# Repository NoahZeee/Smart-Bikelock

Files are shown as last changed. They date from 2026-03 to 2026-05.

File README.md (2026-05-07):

# Smart Bike Lock - WiFi Hotspot Edition

A secure, wireless bike lock system controlled via a mobile web interface. Connect from any iOS or Android device to unlock/lock your bike through a dedicated WiFi hotspot.

## Features

- **📱 Mobile Web Interface**: Responsive web UI works on iOS, Android, and any browser
- **🔒 Password Protected**: Set custom passwords for lock control
- **📡 WiFi Hotspot**: Creates a local WiFi network (no internet required)
- **🔋 Deep Sleep**: Automatically sleeps after 5 minutes of inactivity for battery efficiency
- **💾 Persistent State**: Password and lock state saved to flash memory
- **⚡ Fast Control**: HTTP REST API with instant response times
- **🤖 Offline Operation**: No backend server or cloud connection required

## Hardware

- **Microcontroller**: ESP32 DOIT DevKit V1 (240MHz, 320KB RAM, 4MB Flash)
- **Motor**: 28BYJ-48 stepper motor with ULN2003A driver
- **Wakeup**: GPIO18 external interrupt (HIGH level trigger) or button press
- **GPIO Pins**:
  - Motor: 13, 25, 14, 26
  - Wakeup: 18
  - USB: COM6 (configurable in platformio.ini)

## Manufacturing Files

All files needed to manufacture the PCB and order parts are located in the **`hardware/`** directory:

### Schematics & PCB Layout
- **Location**: `hardware/schematics/`
- **Files**:
  - `RFID_bikelock.kicad_sch` - Schematic diagram
  - `RFID_bikelock.kicad_pcb` - PCB layout
  - `RFID_bikelock.csv` - Bill of Materials (BOM) - use this to order parts

### Gerber Files (for manufacturing)
- **Location**: `hardware/manufacturing/`
- **Files**:
  - `RFID_bikelock-F_Cu.gbr` - Front copper layer
  - `RFID_bikelock-B_Cu.gbr` - Back copper layer
  - `RFID_bikelock-F_Mask.gbr` - Front solder mask
  - `RFID_bikelock-B_Mask.gbr` - Back solder mask
  - `RFID_bikelock-F_Silkscreen.gbr` - Front silkscreen
  - `RFID_bikelock-B_Silkscreen.gbr` - Back silkscreen
  - `RFID_bikelock-Edge_Cuts.gbr` - Board edge cuts
  - `RFID_bikelock-job.gbrjob` - Gerber job file

### Drill Files
- **Location**: `hardware/manufacturing/`
- **Files**:
  - `RFID_bikelock-PTH.drl` - Plated through-hole drilling
  - `RFID_bikelock-NPTH.drl` - Non-plated through-hole drilling

### To Order PCBs
1. Use the Gerber files and drill files in `hardware/manufacturing/` 
2. Upload all files to your PCB manufacturer (JLCPCB, PCBWay, etc.)
3. Use the BOM (`hardware/schematics/RFID_bikelock.csv`) to order components

## Getting Started

### Prerequisites

- PlatformIO CLI or VS Code with PlatformIO extension
- USB cable for ESP32 upload
- Your smartphone on WiFi

### Building & Uploading

```bash
# Build firmware
platformio run

# Upload to ESP32
platformio run -t upload

# Monitor serial output
platformio run -t monitor
```

### Initial Setup

1. Serial monitor will display initialization sequence
2. Connect to WiFi network: `BikelockAP` (open network, no password)
3. Visit `http://192.168.4.1` from your phone
4. Set a password in the web UI (device will lock automatically)
5. Now you can lock/unlock with your password!

## Web UI Controls

- **Status Display**: Shows current lock state (🔒 LOCKED / 🔓 UNLOCKED)
- **Password Field**: Enter your password
- **Unlock Button**: Unlock the lock (requires correct password)
- **Lock Button**: Lock the device (only works when unlocked)
- **Set Password**: Set a new password and lock device
- **Refresh**: Manually refresh lock status
- **Reset Device**: Factory reset (clears password)

## REST API

All endpoints are available at `http://192.168.4.1`

### GET /status
Returns current lock state
```json
{"status": "LOCKED"}  // or "UNLOCKED"
```

### POST /unlock
Unlock with password
```json
Request: {"password": "your_password"}
Response: {"status": "UNLOCKED"}  // or stays "LOCKED" if password wrong
```

### POST /lock
Lock the device (requires password already set)
```json
Response: {"status": "LOCKED"}
```

### POST /set-password
Set new password and lock device
```json
Request: {"password": "new_password"}
Response: {"status": "LOCKED"}
```

### POST /reset
Factory reset device (clears password, unlocks)
```json
Response: {"status": "UNLOCKED"}
```

## Configuration

Edit `include/config.h` to customize:

- **WiFi Network**: `WIFI_SSID` and `WIFI_PASSWORD` (empty = open network)
- **Deep Sleep Timeout**: `INACTIVITY_TIMEOUT_MS` (default: 5 minutes)
- **Motor Rotation**: `STEPPER_LOCK_STEPS` and `STEPPER_UNLOCK_STEPS`
- **GPIO Pins**: All pin definitions
- **SPIFFS**: Flash partition configuration

## Project Structure

```
src/
├── main.cpp              # Setup and main event loop
├── wifi_server.cpp       # WiFi hotspot initialization
├── http_handlers.cpp     # HTTP endpoint handlers
├── commands.cpp          # Command processing logic
├── lock_control.cpp      # Stepper motor control
├── flash_storage.cpp     # SPIFFS persistence
└── globals.cpp           # Global variable definitions

include/
├── config.h              # Central configuration
├── globals.h             # Global declarations
├── web_ui.h              # Embedded HTML/CSS/JS UI
├── wifi_server.h         # WiFi function declarations
├── http_handlers.h       # HTTP handler declarations
├── commands.h            # Command processing declarations
├── lock_control.h        # Motor control declarations
└── flash_storage.h       # Storage function declarations
```

## How It Works

### Initialization Flow
1. ESP32 boots and mounts SPIFFS filesystem
2. Loads stored password and lock state from flash
3. Initializes stepper motor and rotates to match stored state
4. Enables GPIO18 for external wakeup (5V HIGH trigger)
5. Starts WiFi in Access Point (hotspot) mode
6. HTTP server listening on port 80
7. Enters main loop checking for inactivity

### Unlock Flow
1. User enters password in web UI
2. Browser sends POST to `/unlock` with JSON body
3. Server validates password matches stored value
4. If correct: rotates motor to unlock position, saves state
5. If incorrect: returns current state (still LOCKED)
6. Browser receives response and updates UI accordingly

### Deep Sleep
- Device sleeps after 5 minutes with no WiFi activity
- Can be woken by:
  - GPIO18 going HIGH (button press or external trigger)
  - Web request (resets 5-minute timer)
- Uses RTC memory to preserve WiFi config across sleep

## Firmware Optimization

- **Size**: 1.01 MB (77% of 4MB flash)
- **Memory**: Manual JSON parsing (no ArduinoJson)
- **UI**: Embedded in firmware (no SPIFFS file serving)
- **Removed**: BLE module (replaced with WiFi)

## Troubleshooting

### Web UI not loading
- Ensure you're connected to `BikelockAP` WiFi
- Check that IP is `192.168.4.1`
- Verify serial monitor shows "HTTP Server started on port 80"

### Unlock not working
- Verify password is correct (serial shows "Incorrect password" on failure)
- Check that a password has been set first
- Try Reset Device if needed

### Device not waking from sleep
- Verify GPIO18 connection (should go HIGH on button press)
- Check serial monitor for "Wake reason" message
- May need to press button longer or adjust trigger level

### Firmware upload fails
- Close serial monitor first
- Try `platformio run --target clean` then rebuild
- Check COM port in `platformio.ini`

## Authors

Noah Zacharia, Peter Luster, Kirollos Melek

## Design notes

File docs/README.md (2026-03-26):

# Smart Bike Lock - Web App Setup & Deployment Guide

## Overview
This web app connects to your ESP32-based Bike Lock via Web Bluetooth API. It provides a mobile-friendly interface to control your lock remotely.

## Features
✅ **Direct Bluetooth Connection** - No backend relay needed  
✅ **Mobile-First Design** - Optimized for phone use  
✅ **Real-Time Status Updates** - Live lock status via BLE notifications  
✅ **Secure Commands** - SET, UNLOCK, LOCK, STATUS, RESET  
✅ **Responsive Layout** - Works on all screen sizes  
✅ **Dark Mode Support** - Automatic based on system preferences  

## Requirements
- **ESP32 Firmware**: Must be flashed with the updated main.cpp (includes SPIFFS and deep sleep support)
- **Browser Support**: Chrome, Edge, or similar (Chromium-based) on:
  - Android (native support)
  - macOS/iOS (iOS 17+, needs app wrapper)
  - Desktop Linux/Windows (requires compatible BLE adapter)
- **Permissions**: Your phone will need to allow Bluetooth access

## Deployment Options

### Option 1: Static Hosting (Recommended)
Host the web app files on a static file server. Users visit a URL to access it.

#### Services:
- **GitHub Pages** (free): Upload to a gh-pages branch
- **Firebase Hosting** (free tier available)
- **Netlify** (free tier available)
- **AWS S3 + CloudFront** (pay-as-you-go)
- Public Dropbox link or similar

#### Steps:
1. Upload `index.html`, `style.css`, and `app.js` to your hosting service
2. Share the URL with users
3. Users open the URL in their browser on a phone/device with Bluetooth and the capability

**Example GitHub Pages:**
```bash
# In your bikelock repository root
mkdir docs
cp web/* docs/
git add docs/
git commit -m "Add web app"
git push origin main

# Then enable GitHub Pages in Settings → Pages → Deploy from a branch → docs folder
```

### Option 2: Local Testing (for development)
Run a simple HTTP server on your computer:

```bash
# From the web/ directory
python -m http.server 8000

# Then visit: http://localhost:8000
```

> **Note**: Web Bluetooth requires HTTPS or localhost. Public HTTP sites won't have BLE access.

### Option 3: Serve from ESP32 (Advanced)
Embed the web app files directly on the ESP32 and serve via HTTP.

This requires additional libraries (ESPAsyncWebServer) and SPIFFS modifications. Recommended for later iteration.

## Usage Instructions

### For End Users:

1. **Power on the ESP32** - Device will start advertising as "Bike Lock"
2. **Open the web app** - Visit the hosted URL on your phone browser
3. **Click "Connect to Lock"** - Browser will show a Bluetooth device picker
4. **Select "Bike Lock"** - Confirm the pairing
5. **Set a password** - Enter a secure 4+ character password and click "Set Password"
6. **Control your lock** - Use LOCK/UNLOCK buttons with your password

### Commands Reference:
| Command | Function |
|---|---|
| **Set Password** | Initialize or change the lock password |
| **Lock** | Engage the lock (no password needed after setup) |
| **Unlock** | Disengage the lock (requires correct password) |
| **Check Status** | Query current lock state |
| **Reset Device** | Clear password and reset device |

## Web App Files

- **index.html** - UI structure (buttons, inputs, status display)
- **style.css** - Mobile-first responsive styling + dark mode
- **app.js** - Web Bluetooth client logic and command handling

## BLE Protocol

### Service UUID
```
1ea28c9d-23ce-4f5b-9290-8b72317b97c3
```

### Characteristics

**Command Characteristic** (WRITE-only)
- UUID: `5a87b3d0-7c7d-4c5b-bf2c-5e7a0f1a0a01`
- Send: `SET [password]`, `UNLOCK [password]`, `LOCK`, `STATUS`, `RESET`

**Status Characteristic** (READ + NOTIFY)
- UUID: `5a87b3d0-7c7d-4c5b-bf2c-5e7a0f1a0a02`
- Receive: `LOCKED`, `UNLOCKED`, `WRONG_PASS`, `RESET`

## Troubleshooting

### Web app opens but no "Connect" button responds
- **Cause**: Web Bluetooth not available on this device/browser
- **Fix**: Use Chrome/Edge on Android or macOS 10.15+

### Can't find the Bike Lock device
- **Cause**: ESP32 not powered or not advertising
- **Fix**: Check ESP32 serial output; verify device is within Bluetooth range (~10m)

### Connection drops frequently
- **Cause**: Interference or range issue
- **Fix**: Move closer to the device; reduce obstacles

### Wrong password keeps showing
- **Cause**: Typo or device not set up yet
- **Fix**: Re-run "Set Password" to initialize

### Device goes to sleep and can't reconnect
- **Cause**: 30-second inactivity timer engaged; device in deep sleep
- **Fix**: Press GPIO12 or GPIO13 touch button to wake; reconnect

## Security Notes

⚠️ **Current Implementation**: Password stored in **plain text** on ESP32 flash  
🔐 **Future Improvement**: Consider AES encryption for production use  

## ESP32 Deep Sleep & Wake

The ESP32 will enter deep sleep after **30 seconds of inactivity** (no BLE commands).

### To Wake the Device:
- **Press GPIO12 touch pin** OR
- **Press GPIO13 touch pin**  
- Device will resume BLE advertising within 1-2 seconds

### Power Consumption:
- **Active**: ~100mA
- **Sleep**: <1mA

This enables months of battery operation if powered by a coin cell or small rechargeable battery.

## Future Enhancements

- [ ] Add support for motor control (future replacement for LED)
- [ ] Implement encrypted password storage (AES)
- [ ] Multi-device support (device directory)
- [ ] Backend system for lost device tracking
- [ ] Mobile app wrapper (React Native or Flutter)
- [ ] Activity logging and audit trail

## Support

For issues, check:
1. ESP32 serial console output
2. Browser console (F12 → Console tab)
3. Bluetooth device list (Settings → Bluetooth)

## Files Modified in Main Project

- `platformio.ini` - Added SPIFFS library
- `include/config.h` - Added flash storage & sleep constants
- `src/main.cpp` - Added flash persistence, deep sleep, RESET command
- `/web/` - All new web app files

---

**Happy locking! 🚲🔒**

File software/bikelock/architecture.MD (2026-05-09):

# Smart Bike Lock - Software Architecture

## System Architecture Diagram

```mermaid
graph TB
    subgraph Hardware["🔧 Hardware Layer"]
        GPIO["GPIO Pins"]
        LED["LED<br/>GPIO 2"]
        STEPPER["Stepper Motor<br/>GPIO 13,25,14,26"]
        WAKE["Touch Wake Pin<br/>GPIO 18,15"]
        USB["USB CDC<br/>Serial"]
        WIFI["WiFi Radio<br/>802.11 b/g/n"]
    end
    
    subgraph Storage["💾 Storage Layer"]
        SPIFFS["SPIFFS<br/>File System"]
        FLASH["Flash Memory<br/>4MB N4"]
        PASSWORD["Stored Password"]
        LOCKSTATE["Lock State"]
    end
    
    subgraph Core["🎯 Core Modules"]
        CONFIG["config.h<br/>Pin & WiFi Defs"]
        GLOBALS["globals.h<br/>Shared Variables"]
        LOCK_CTRL["lock_control.cpp<br/>Motor & State"]
        FLASH_STG["flash_storage.cpp<br/>Read/Write"]
        COMMANDS["commands.cpp<br/>CLI Commands"]
    end
    
    subgraph Network["🌐 Network Stack"]
        WIFI_SRV["wifi_server.cpp<br/>AP Mode"]
        HTTP["http_handlers.cpp<br/>REST API"]
        ROUTES["Routes<br/>/status /lock /unlock<br/>/set-password /reset"]
    end
    
    subgraph Power["⚡ Power Management"]
        SLEEP["esp_sleep.h<br/>Deep Sleep Control"]
        INACTIVITY["Inactivity Timer<br/>1 minute"]
        WAKEUP["External Interrupt<br/>GPIO18 HIGH"]
    end
    
    subgraph Main["▶️ Main Loop"]
        SETUP["setup()"]
        LOOP["loop()"]
    end
    
    SETUP -->|Initialize| CONFIG
    SETUP -->|Mount| SPIFFS
    SETUP -->|Load| FLASH_STG
    SETUP -->|Configure GPIO| GPIO
    SETUP -->|Enable AP| WIFI_SRV
    SETUP -->|Register Routes| HTTP
    
    LOOP -->|Monitor| INACTIVITY
    LOOP -->|Handle| HTTP
    LOOP -->|Check| SLEEP
    
    HTTP -->|GET| LOCK_CTRL
    HTTP -->|POST| LOCK_CTRL
    ROUTES -->|Authenticate| FLASH_STG
    
    LOCK_CTRL -->|Control| STEPPER
    LOCK_CTRL -->|Persist| FLASH_STG
    LOCK_CTRL -->|Indicate| LED
    
    FLASH_STG -->|Read/Write| SPIFFS
    SPIFFS -->|Store| FLASH
    FLASH -->|Hold| PASSWORD
    FLASH -->|Hold| LOCKSTATE
    
    WIFI_SRV -->|Communicate| WIFI
    HTTP -->|Transport| WIFI
    
    SLEEP -->|Trigger| WAKEUP
    WAKEUP -->|Wake from| SLEEP
    INACTIVITY -->|Activate| SLEEP
    
    USB -->|Debug Output| SETUP
    USB -->|Debug Output| LOOP
```

## User Interaction Flow

```mermaid
graph LR
    USER["📱 Mobile App<br/>or Browser"]
    
    subgraph Device["ESP32-S3 Bike Lock"]
        WIFI_AP["WiFi AP<br/>BikelockAP"]
        REST["REST API<br/>Port 80"]
        AUTH["Password<br/>Authentication"]
        LOCK_SM["Lock State<br/>Machine"]
        MOTOR["Stepper<br/>Motor"]
    end
    
    USER -->|Connect to AP| WIFI_AP
    USER -->|HTTP Request| REST
    REST -->|Verify Password| AUTH
    AUTH -->|/lock<br/>/unlock| LOCK_SM
    LOCK_SM -->|Rotate| MOTOR
    REST -->|/status| LOCK_SM
    REST -->|/set-password| AUTH
    REST -->|/reset| LOCK_SM
    
    LOCK_SM -->|Save State| FLASH["Flash Storage"]
    AUTH -->|Save Password| FLASH
```

## How to Export These Diagrams

### Option 1: View Online (Easiest)
1. Go to https://mermaid.live
2. Copy the Mermaid code from the code blocks above
3. Paste into the editor
4. Click "Export" → "Download SVG/PNG"

### Option 2: Use VS Code Extension
1. Install "Markdown Preview Mermaid Support" extension
2. Open this file in preview mode (Ctrl+Shift+V)
3. Right-click on diagram → "Save Image As"

### Option 3: Use Command Line (Requires npm)
```bash
npm install -g @mermaid-js/mermaid-cli
mmdc -i ARCHITECTURE.md -o architecture.svg
```

## Architecture Overview

### Hardware Layer
- **LED (GPIO 2)**: Connection indicator
- **Stepper Motor (GPIO 13, 25, 14, 26)**: Physical lock mechanism
- **Wake Pins (GPIO 18, 15)**: External interrupt for deep sleep wakeup
- **USB CDC**: Native serial communication over USB
- **WiFi Radio**: 802.11 b/g/n access point

### Storage Layer
- **SPIFFS**: File-based storage on flash
- **Flash Memory**: 4MB N4 variant (192KB SPIFFS, 1.75MB app code)
- **Stored Password**: Hashed password for authentication
- **Lock State**: Persisted lock status (locked/unlocked)

### Core Modules
- **config.h**: Pin definitions and WiFi configuration constants
- **globals.h**: Shared global variables and extern declarations
- **lock_control.cpp**: Motor control and lock state management
- **flash_storage.cpp**: SPIFFS read/write operations
- **commands.cpp**: CLI command processing

### Network Stack
- **wifi_server.cpp**: Access point (AP) mode initialization
- **http_handlers.cpp**: REST API endpoint handlers
- **Routes**: 5 HTTP endpoints for control and status

### Power Management
- **esp_sleep.h**: Deep sleep configuration
- **Inactivity Timer**: 1 minute of inactivity triggers sleep
- **External Wakeup**: GPIO18 pulled HIGH wakes from sleep

### Main Loop
- **setup()**: Initializes all modules and peripherals
- **loop()**: Handles HTTP requests and monitors inactivity for sleep

## Data Flow

### Lock Operation
```
HTTP Request → Authenticate Password → updateLockState() 
→ Control Stepper Motor → LED Indicator → Save to Flash
```

### Query Status
```
HTTP GET /status → Read Lock State from Memory → Return JSON
```

### Change Password
```
HTTP POST /set-password → Validate → Store Hashed Password → Lock Device
```

### Power Saving
```
Inactivity Detected (1 min) → Disable WiFi → Enter Deep Sleep 
→ GPIO18 HIGH → External Interrupt → Wake & Reinit
```

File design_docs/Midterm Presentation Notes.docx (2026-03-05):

# BLUETOOTH Bike Lock

# Function/Purpose:

This project designs a smart bike lock that uses Bluetooth and an ESP32 instead of traditional keys or mechanical combinations. The rider uses their phone to connect to the ESP32 via Bluetooth. An LED indicates whether the locking system is engaged.

A locking mechanism is used to lock or unlock the bike physically.

The goal is to create a convenient, modern, and tamper‑resistant lock that showcases wireless communication and electromechanical design.

## Consideration:

Type of locking mechanism that will be used (must be compatible with the microcontroller voltage output)

Power Management- power efficiency and how to use sleep mode to maximize battery life.

Security risks- Avoid accepting commands from unknown or unauthorized devices.

Microcontroller used-ESP32:

Microcontroller family: ESP32 (32‑bit MCU with integrated Wi‑Fi and Bluetooth)

Key characteristics:

- Dual‑core 32‑bit processor
- Built‑in Bluetooth Classic / BLE for wireless communication with smartphones
- Sufficient GPIO pins to drive actuators, LEDs, buzzer, and read sensors
- Low‑power modes suitable for battery‑operated devices

Description:

Work in Progress:

For our RFID bike lock, we focused on how to maximize battery life while keeping the system reliable and simple.

We considered two main approaches: solar charging and low-power sleep mode.

The first option was to use a solar panel to recharge the battery, where energy would flow from the solar panel to a charge controller, then to the battery that powers the system. While this could extend battery life, it also adds hardware complexity and may not always work well because bikes are often parked in shaded areas.

The second option was to use the microcontroller’s deep sleep mode to reduce power consumption. In this approach, the system stays in a very low-power state most of the time. When a user interacts with the lock, the microcontroller wakes up, powers the RFID reader, scans for a tag, and unlocks the bike if the tag is authorized. Afterward, the system powers down again.

Our strategy is to prioritize low-power sleep mode, since it keeps the design simpler and more reliable. Solar charging could still be added later as an optional feature to further extend battery life.”

## POC prototype details:

- Quickly discovered that RFID was more difficult than easier alternatives
  - BLE (Bluetooth Low-Energy) is the way to go for now
- ESP32 sets up a BLE service that can be connected to by any other device with BLE (iPhone)
- Instead of turning a lock, we have 2 LEDs to represent locked and unlocked state
- Use the LightBlue app on iOS to connect to esp32
  - BLE characteristics: Set and reset password, and lock/unlock, and check status

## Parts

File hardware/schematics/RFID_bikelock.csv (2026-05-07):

Designator | Qty | Value | Footprint | MPN | Datasheet
C1,C6,C10,C11 | 4 | 10uF | Capacitor_SMD:C_0805_2012Metric_Pad1.18x1.45mm_HandSolder | CL21A106KOQNNNE | ~
C2,C4,C5 | 3 | 1uF | Capacitor_SMD:C_0603_1608Metric_Pad1.08x0.95mm_HandSolder | CL10B105KA8NNNC | ~
C3,C7,C8,C9,C12 | 5 | 0.1uF | Capacitor_SMD:C_0603_1608Metric_Pad1.08x0.95mm_HandSolder | CL10B104KB8NNNC | ~
C13 | 1 | 10 uF | Capacitor_SMD:C_0805_2012Metric_Pad1.18x1.45mm_HandSolder | CL21A106KOQNNNE | ~
C14 | 1 | 4.7uF | Capacitor_SMD:C_0603_1608Metric_Pad1.08x0.95mm_HandSolder | CL10A475KP8NNNC | ~
D3 | 1 | ESP-PWR | LED_SMD:LED_0805_2012Metric_Pad1.15x1.40mm_HandSolder | LTST-C170GKT | ~
D5 | 1 | Pwr_Good | LED_SMD:LED_0805_2012Metric_Pad1.15x1.40mm_HandSolder | LTST-C170GKT | ~
D6 | 1 | STAT1 | LED_SMD:LED_0805_2012Metric_Pad1.15x1.40mm_HandSolder | LTST-C170GKT | ~
D7 | 1 | STAT2 | LED_SMD:LED_0805_2012Metric_Pad1.15x1.40mm_HandSolder | LTST-C170GKT | ~
H1,H2,H3,H4 | 4 | MountingHole_Pad | MountingHole:MountingHole_3.2mm_M3_Pad |  | ~
H5,H6 | 2 | MountingHole | MountingHole:MountingHole_3.2mm_M3 |  | ~
J1 | 1 | BATT_p2+ | Connector_PinHeader_2.54mm:PinHeader_1x02_P2.54mm_Vertical |  | ~
J2 | 1 | USB_prog | Connector_USB:USB_Micro-B_Amphenol_10118194_Horizontal |  | ~
J3 | 1 | motor_out | Connector_PinHeader_2.54mm:PinHeader_1x05_P2.54mm_Vertical |  | ~
J5 | 1 | GPIO out | Connector_PinSocket_2.54mm:PinSocket_1x08_P2.54mm_Vertical |  | ~
J6 | 1 | WAKE_IN_OUT | Connector_PinSocket_2.54mm:PinSocket_1x02_P2.54mm_Vertical |  | ~
L1 | 1 | 2.2 uH | Inductor_SMD:L_1008_2520Metric | MAMK2520T2R2M | ~
R1,R_TH1 | 2 | 10k | Resistor_SMD:R_0603_1608Metric_Pad0.98x0.95mm_HandSolder | RMCF0603FT10K0 | ~
R2 | 1 | 100 | Resistor_SMD:R_0603_1608Metric_Pad0.98x0.95mm_HandSolder | RC0603FR-07100RL | ~
R4,R8 | 2 | 1k | Resistor_SMD:R_0603_1608Metric_Pad0.98x0.95mm_HandSolder | RMCF0603FT1K00 | ~
R6,R9,R10,R11 | 4 | 470 | Resistor_SMD:R_0603_1608Metric_Pad0.98x0.95mm_HandSolder | RC0603JR-07470RL | ~
R_Prog1 | 1 | 2k | Resistor_SMD:R_0603_1608Metric_Pad0.98x0.95mm_HandSolder | RC0603FR-072KL | ~
R_Prog3 | 1 | 20k | Resistor_SMD:R_0603_1608Metric_Pad0.98x0.95mm_HandSolder | RC0603FR-0720KL | ~
SW1 | 1 | EN | Button_Switch_THT:SW_PUSH_6mm |  | ~
SW2 | 1 | BOOT | Button_Switch_THT:SW_PUSH_6mm |  | ~
SW3 | 1 | WAKE | Button_Switch_THT:SW_PUSH_6mm |  | ~
TP1 | 1 | Vsys | TestPoint:TestPoint_Pad_D3.0mm |  | ~
TP2 | 1 | GND | TestPoint:TestPoint_Pad_D3.0mm |  | ~
TP3 | 1 | 3V3 | TestPoint:TestPoint_Pad_D3.0mm |  | ~
TP4 | 1 | 5V | TestPoint:TestPoint_Pad_D3.0mm |  | ~
U1 | 1 | ULN2003 | Package_DIP:CERDIP-16_W7.62mm_SideBrazed_LongPads | ULN2003A | http://www.ti.com/lit/ds/symlink/uln2003a.pdf
U2 | 1 | ESP32-S3-WROOM-1 | RF_Module:ESP32-S3-WROOM-1 | ESP32-S3-WROOM-1-N4 | https://www.espressif.com/sites/default/files/documentation/esp32-s3-wroom-1_wroom-1u_datasheet_en.pdf
U3 | 1 | ADPL40502AUJZ-3.3-R7 | my_lib:ADPL40502-3V3 | ADPL40502AUJZ-3.3-R7 | ADPL40502AUJZ-3.3-R7
U4 | 1 | TPS63002 | Package_SON:Texas_DRC0010J_ThermalVias | TPS63002DRCR | http://www.ti.com/lit/ds/symlink/tps63000.pdf
U6 | 1 | MCP73871-2CC | Package_DFN_QFN:QFN-20-1EP_4x4mm_P0.5mm_EP2.5x2.5mm | MCP73871-2CCI/ML | http://www.mouser.com/ds/2/268/22090a-52174.pdf

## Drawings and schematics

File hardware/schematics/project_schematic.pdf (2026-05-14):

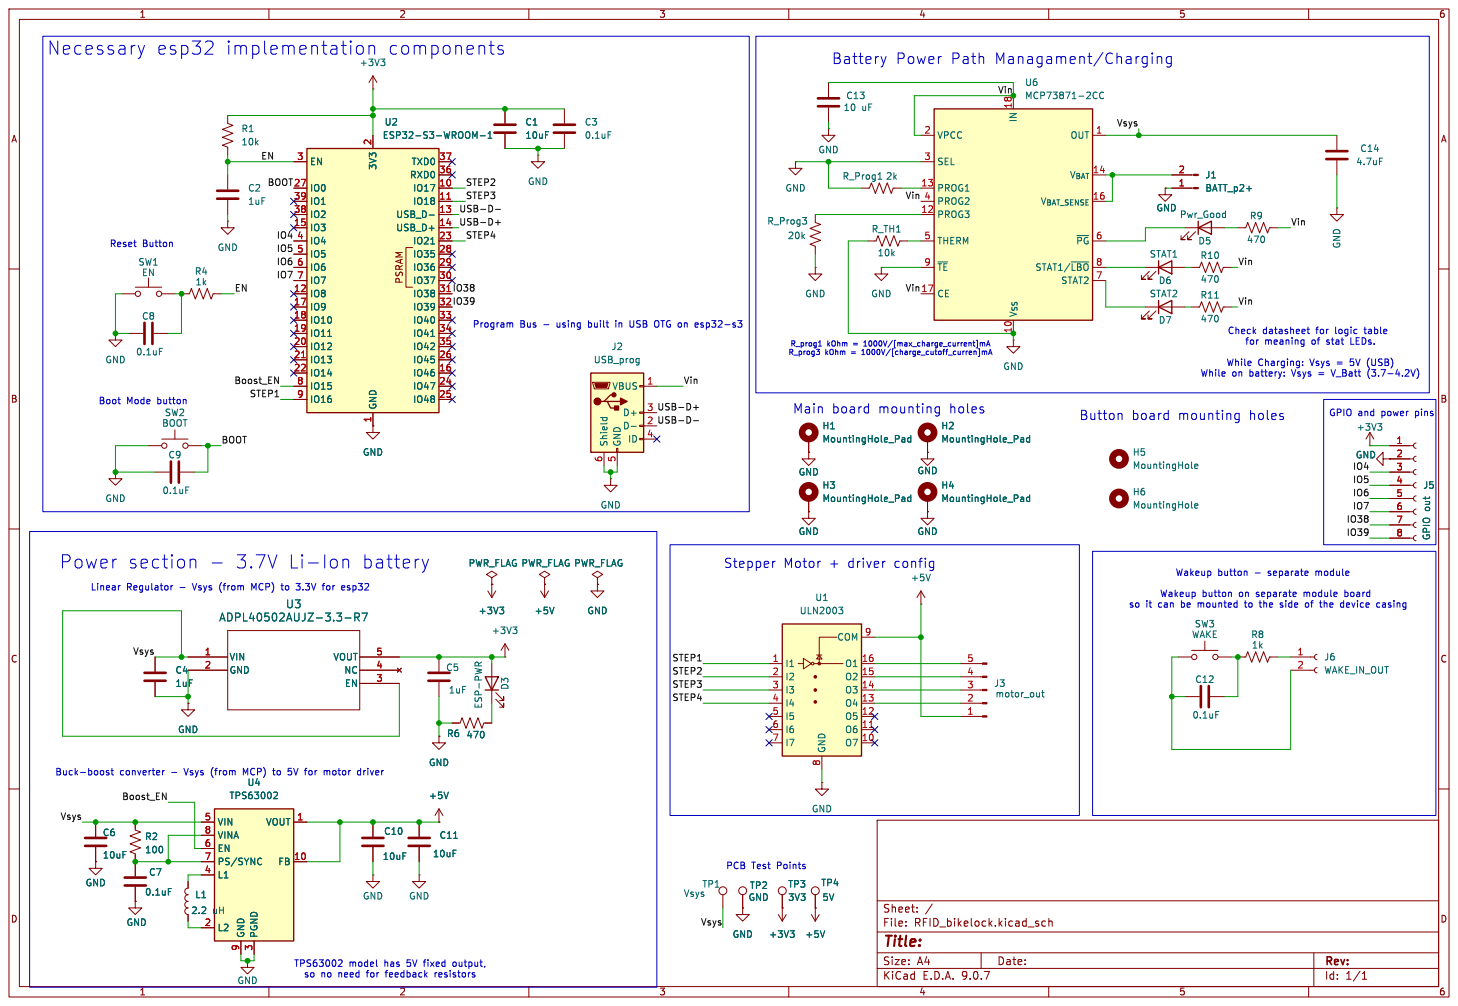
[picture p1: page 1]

Wakeup button - separate module Battery Power Path Managament/Charging

2 GND
20k GND GND GND PSRAM

Wakeup button on separate module board

3 VOUT 1 FB 10 GND GND

Id: 1/1 Title: File: RFID_bikelock.kicad_sch Sheet: /

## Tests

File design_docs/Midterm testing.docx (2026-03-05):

# Prototype 1 testing

BLE + LED model

## Test 1

- We just wanted to verify that we could set up a BLE server and connect to it from a phone
- Used the built-in LED on the esp32 dev board to verify connection

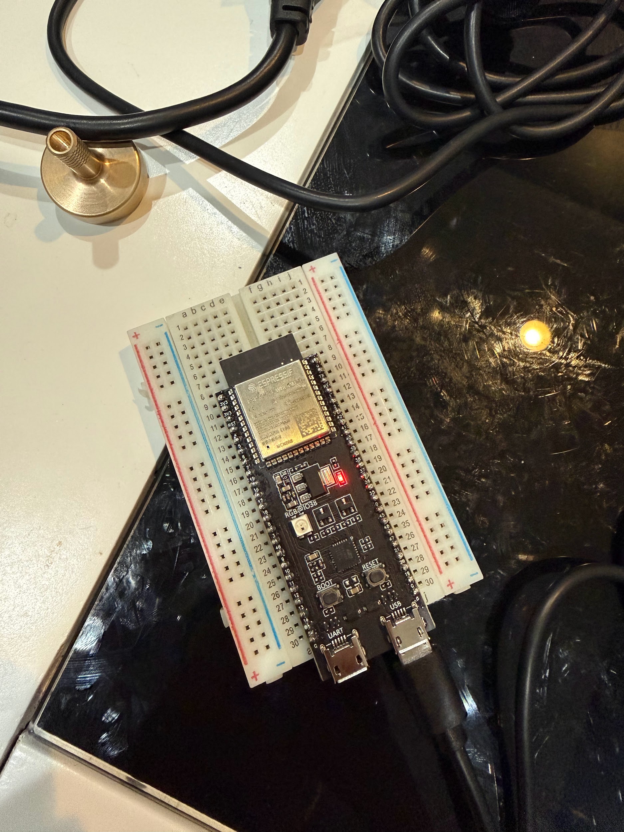
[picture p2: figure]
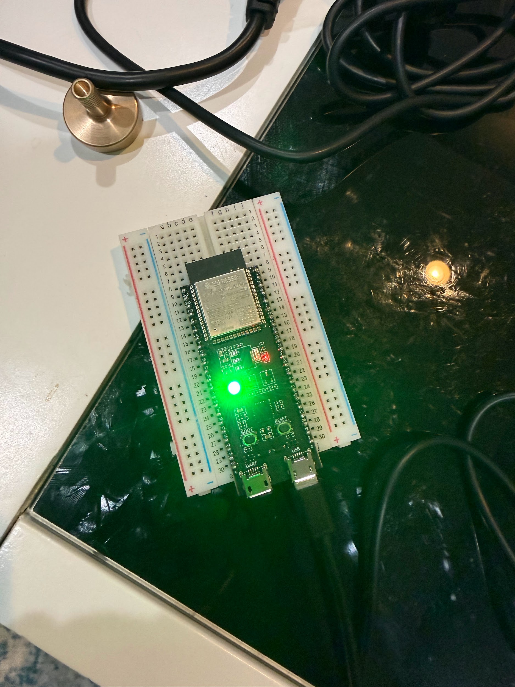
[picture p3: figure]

(without connecting) (after connecting)

## Test 2

- This test was done with “full” functionality (for this POC prototype)
- LEDs indicate locked or unlocked status, as well as bluetooth connection status (still the built in LED)

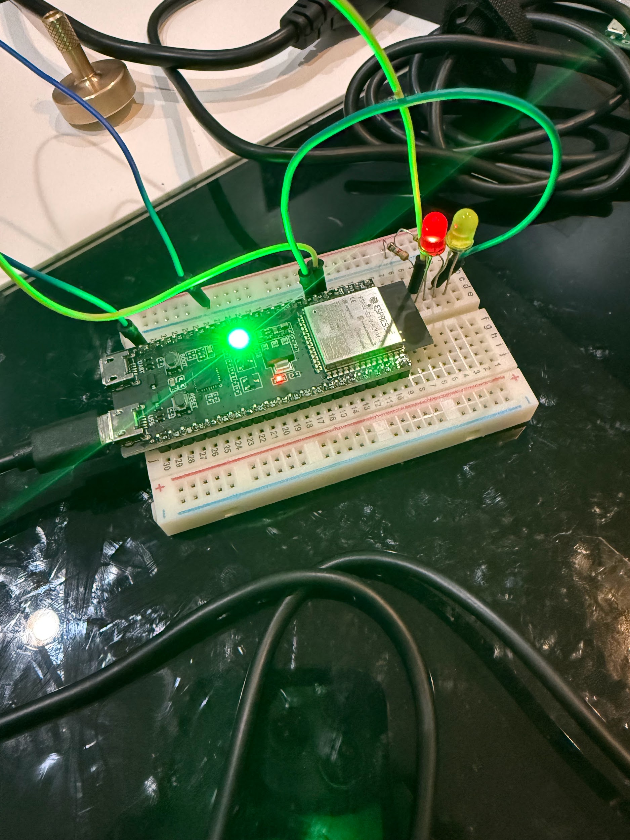
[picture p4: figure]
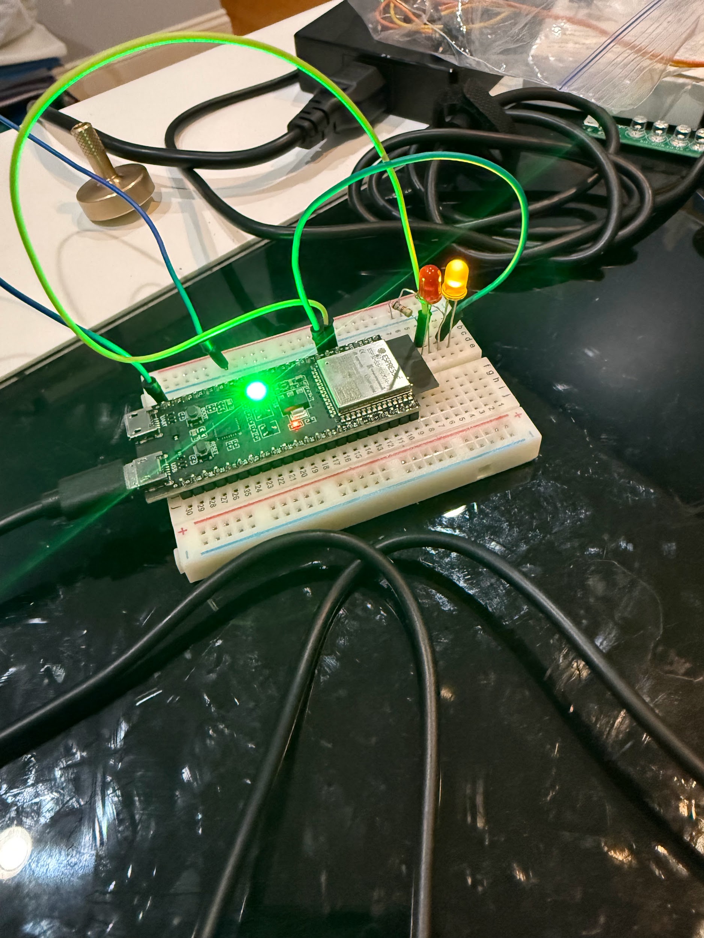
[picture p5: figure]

(device connected, unlocked [yellow on]) (device connected, locked [red on])

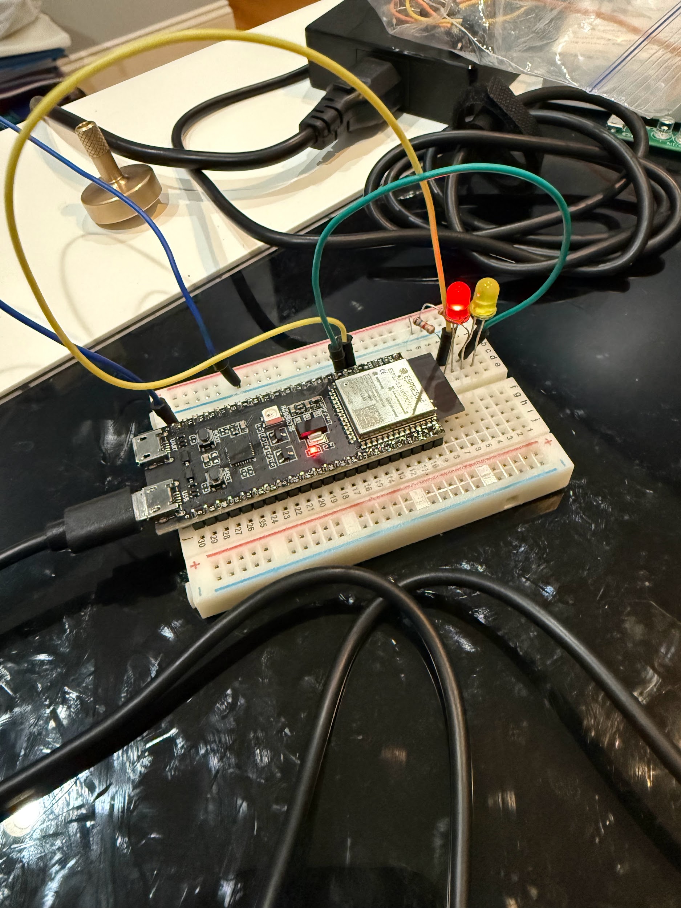
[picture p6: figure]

Here, we can see how the lock remains locked even when the device is disconnected (red LED on, built-in LED off)

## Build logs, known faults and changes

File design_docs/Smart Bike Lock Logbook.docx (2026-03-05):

# Project Logbook: Smart Bike Lock – BLE Prototype

Students: Noah Zacharia, Peter Luster, Kirollos Melek

Project Title: Smart Bike Lock – Bluetooth Control Prototype

# Project Overview

The goal of this project is to design and prototype a smart bike lock controlled via a microcontroller (ESP32) over Bluetooth Low Energy (BLE).

The system allows a user to:

- Set a password to lock the bike
- Unlock the bike with the correct password
- Check the lock status
- Receive feedback via LED indicators

Initially, the project aimed to use RFID-based lock control, but after testing feasibility, the design pivoted to BLE due to reliability, ease of smartphone integration, and real-time feedback.

# Project Log Entries

## Entry 1

Initial Concept & Design Decisions | Week of Feb 1 -

- Idea - use RFID cards / tags to unlock a bike lock
- Challenges identified: iPhone cannot emulate arbitrary RFID tags easily; limited range for NFC/RFID
- Potentially explore other methods of unlocking, such as bluetooth

## Entry 2

Microcontroller Selection | Week of February 15 -

- Selected ESP32 DevKitC-1 initially for BLE support
- Issues encountered: Serial monitor did not work due to USB CDC limitations on S3 board. - Workaround: Proceed with LED feedback testing and BLE notifications; use BLE to simulate debugging messages.

## Entry 3

BLE Architecture | Week of March 1

- Created BLE server on ESP32 with:
  - Service UUID for the bike lock
  - Command characteristic (write-only) for lock/unlock/set password
  - Status characteristic (read/notify) to report lock state and debug messages
  - Implemented password-based authentication via BLE commands
  - LED indicators: Red = locked, Yellow = unlocked.

## Entry 4

Command Structure & Testing | Week of March 1

- Designed BLE command syntax for mobile app: SET 1234, UNLOCK 1234, LOCK, STATUS.
- Tested with LightBlue app
- Verified LEDs changed correctly based on command and password validation
- Learned JSON commands were too cumbersome on mobile devices; simplified syntax improves usability.

## Entry 5

Serial Debugging Challenges | Week of March 1

- Attempted Serial.println() for debugging
- On ESP32-S3: no serial output visible in PlatformIO
- We will probably have to use a different dev board, but that is fine since the one we chose is a little large

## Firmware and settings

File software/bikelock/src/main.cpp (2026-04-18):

/*
 * Smart Bike Lock - ESP32 WiFi Hotspot Server
 * 
 * A secure bike lock system with:
 * - WiFi hotspot connectivity for mobile apps
 * - SPIFFS-based password and state persistence
 * - Deep sleep after 30s inactivity
 * - Stepper motor control
 * 
 * Authors: Noah Z, Peter S, Kirollos M
 */

// TODO test deep sleep wakeup functionality

#include <Arduino.h>
#include <config.h>
#include <SPIFFS.h>
#include <esp_sleep.h>
#include <WiFi.h>

// Module headers
#include <globals.h>
#include <flash_storage.h>
#include <lock_control.h>
#include <commands.h>
#include <wifi_server.h>
#include <http_handlers.h>

/**
 * Initialize the device: SPIFFS, GPIO, and deep sleep configuration
 */
void setup() {
  Serial.begin(115200);
  delay(2000);
  Serial.println("\n\n==================================");
  Serial.println("Bike Lock WiFi Server - Initializing");
  Serial.println("==================================\n");

  // Check if waking from deep sleep
  esp_sleep_wakeup_cause_t wakeup_reason = esp_sleep_get_wakeup_cause();
  if (wakeup_reason == ESP_SLEEP_WAKEUP_EXT0) {
    Serial.println(">>> WOKE UP FROM DEEP SLEEP (External Pin)");
  } else if (wakeup_reason != ESP_SLEEP_WAKEUP_UNDEFINED) {
    Serial.print(">>> WOKE UP FROM DEEP SLEEP (Reason: ");
    Serial.print((int)wakeup_reason);
    Serial.println(")");
  }

  // Initialize SPIFFS
  if (!SPIFFS.begin(true)) {
    Serial.println("SPIFFS Mount Failed");
    return;
  }
  Serial.println("SPIFFS mounted successfully");
  
  // Debug: List SPIFFS contents
  Serial.println("SPIFFS Contents:");
  File root = SPIFFS.open("/");
  File file = root.openNextFile();
  int fileCount = 0;
  while (file) {
    Serial.print("  - ");
    Serial.print(file.name());
    Serial.print(" (");
    Serial.print(file.size());
    Serial.println(" bytes)");
    fileCount++;
    file = root.openNextFile();
  }
  if (fileCount == 0) {
    Serial.println("  (No files found in SPIFFS!)");
  }

  // Load persistent state from flash
  storedPassword = loadPasswordFromFlash();
  bool savedLockState = loadLockStateFromFlash();

  // Configure GPIO pins
  pinMode(LED_PIN, OUTPUT);
  digitalWrite(LED_PIN, LOW);

  stepper.setSpeed(STEPPER_SPEED); // Set stepper motor speed (RPM)

  // Initialize WiFi hotspot
  Serial.println("\n--- WiFi Hotspot Mode Enabled ---");

  // Set initial lock state from saved state
  updateLockState(savedLockState);

  // Configure deep sleep
  Serial.println("\n--- Deep Sleep Configuration ---");
  
  // Configure GPIO18 for external wakeup (HIGH level trigger)
  pinMode(TOUCH_WAKE_PIN_1, INPUT_PULLDOWN);
  esp_sleep_enable_ext0_wakeup((gpio_num_t)TOUCH_WAKE_PIN_1, HIGH);
  
  Serial.println("Deep sleep configured:");
  Serial.print("  Primary wake pin: GPIO");
  Serial.print(TOUCH_WAKE_PIN_1);
  Serial.println(" (HIGH level trigger)");
  Serial.print("  Inactivity timeout: ");
  Serial.print(INACTIVITY_TIMEOUT_MS / 1000);
  Serial.println(" seconds");

  // Initialize WiFi in hotspot mode (if enabled)
  if (WIFI_MODE_ENABLED) {
    initializeWiFi();
    startHTTPServer();
  }

  lastActivityTime = millis();
  Serial.println("\n==================================");
  Serial.println("Initialization Complete - Ready!");
  Serial.println("==================================\n");
}

/**
 * Main event loop: Monitor inactivity and manage deep sleep
 */
void loop() {
  // Handle HTTP requests (if WiFi is enabled)
  if (WIFI_MODE_ENABLED) {
    handleHTTPRequests();
  }

  // Check for inactivity timeout and enter deep sleep if needed
  if ((millis() - lastActivityTime) > INACTIVITY_TIMEOUT_MS) {
    Serial.println("\n========== ENTERING DEEP SLEEP ==========");
    Serial.print("Last activity: ");
    Serial.print(millis() - lastActivityTime);
    Serial.println(" ms ago");
    Serial.print("GPIO18 state before sleep: ");
    Serial.println(digitalRead(TOUCH_WAKE_PIN_1));
    Serial.print("To wake up: Connect GPIO18 to 3.3V");
    Serial.println("");
    Serial.println("========================================\n");
    Serial.flush();
    delay(500); // Allow serial to flush completely

    // Turn off WiFi to save power
    WiFi.mode(WIFI_OFF);
    btStop();
    
    esp_deep_sleep_start();
  }

  delay(1000); // Check every second
}

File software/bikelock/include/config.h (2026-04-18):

#pragma once

/** DEVICE INFO ************************/
#define DEVICE_NAME "Bike Lock"

/** STATUS LED PIN (connection indicator) ************************/
#define LED_PIN 2

/** STEPPER MOTOR CONFIGURATION ************************/
#define STEPPER_PIN_1 13
#define STEPPER_PIN_2 25
#define STEPPER_PIN_3 14
#define STEPPER_PIN_4 26
#define STEPS_PER_REV 2048

// Stepper motor rotation amounts
// Adjust these values based on your lock mechanism
// Positive values = clockwise, negative = counterclockwise
#define STEPPER_LOCK_STEPS 1024      // Steps to rotate when locking (adjust as needed)
#define STEPPER_UNLOCK_STEPS -1024   // Steps to rotate when unlocking (negative of lock)
#define STEPPER_SPEED 10            // RPM speed for stepper motor

/** TOUCH WAKE PINS (for deep sleep) *****/
#define TOUCH_WAKE_PIN_1 18
#define TOUCH_WAKE_PIN_2 15

/** SLEEP CONFIGURATION *****/
#define INACTIVITY_TIMEOUT_MS (1 * 60 * 1000) // 1 minute (60 seconds)

/** SPIFFS CONFIGURATION *****/
#define SPIFFS_MOUNT_POINT "/spiffs"
#define PASSWORD_KEY "bike_lock_pwd"

/** WIFI HOTSPOT CONFIGURATION ************************/
#define WIFI_SSID "BikelockAP"           // WiFi network name
#define WIFI_PASSWORD ""                // WiFi password (empty = open network)
#define WIFI_MODE_ENABLED true           // Enable WiFi hotspot (true/false)
#define HTTP_SERVER_PORT 80              // HTTP port (80 is standard)

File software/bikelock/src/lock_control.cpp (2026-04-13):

#include <lock_control.h>
#include <globals.h>
#include <flash_storage.h>
#include <config.h>

/**
 * Lock Control Module Implementation
 * Stepper motor control with flash persistence
 */

void updateLockState(bool locked) {

  isLocked = locked;
  saveLockStateToFlash(locked); // Persist lock state

  String statusValue = locked ? "LOCKED" : "UNLOCKED";
  
  if (isLocked) { 
    // LOCK: Rotate stepper motor to engage lock
    Serial.println("Rotating stepper motor to engage lock...");
    stepper.step(STEPPER_LOCK_STEPS);
    Serial.print("Lock engaged. Rotated ");
    Serial.print(STEPPER_LOCK_STEPS);
    Serial.println(" steps");
  } else { 
    // UNLOCK: Rotate stepper motor to disengage lock
    Serial.println("Rotating stepper motor to disengage lock...");
    stepper.step(STEPPER_UNLOCK_STEPS);
    Serial.print("Lock disengaged. Rotated ");
    Serial.print(STEPPER_UNLOCK_STEPS);
    Serial.println(" steps");
  }
  Serial.flush();
  
  Serial.print("Lock state: ");
  Serial.println(statusValue);
  Serial.flush();
}

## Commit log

2026-03-03 Add schematic files
    [RFID_bikelock.kicad_pcb, RFID_bikelock.kicad_sch, microcontroller.kicad_sch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]
2026-03-05 added code for BLE server. Added implementation for lock/unlock messages to be sent from phone. Password can be set from phone. Current output is to GPIO (LEDs)
2026-03-05 fixed issue with commands not working, also simplified commands so they make more sense to type on a phone
    [main.cpp]
2026-03-05 Added Files: logbook, POC prototype testing (midterm), and midterm presentation notes
2026-03-05 Added code: added updateLockState() method to streamline lock state changes, also to make it easier in the future when updating the lock state no longer just controls an LED, but actually involves th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
    [main.cpp]
2026-03-11 added header file (config.h) to esp32 source code to make it look cleaner. Will add more header files in future. Edited schematic - not finished. Switched board from esp32-s3-devkit-c1 to esp32-devki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
    [RFID_bikelock.kicad_sch, microcontroller.kicad_sch, servo_assembly.kicad_sch]
2026-03-18 Modified schematics to reflect design choices. Not finished
    [RFID_bikelock.kicad_sch, power_supply.kicad_sch, servo_assembly.kicad_sch]
2026-03-26 feat: Add flash persistence, deep sleep, and web app for smart bike lock
    ## Changes
    ### ESP32 Firmware (Phase 1)
    - Add SPIFFS flash storage for password persistence across power cycles
    - Implement deep sleep after 30s inactivity with GPIO12/GPIO13 touch pin wake
    - Add RESET command to clear stored password
    - Track BLE activity for inactivity detection
    - Password auto-loads on boot and after wake-up
    - Update platformio.ini with SPIFFS library dependency
    - Add sleep and storage configuration constants to config.h
    ### Web App (Phases 2-3)
    - Create mobile-first web application with direct Web Bluetooth connectivity
    - Implement responsive UI optimized for phone use with dark mode support
    - Buil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
    [config.h, main.cpp]
2026-04-01 Fixed: website commands now received and printed to serial monitor, able to connect via bluetooth to service. Changed: updated schematic to inlucde battery charger and finished minimal esp32 design T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
    [RFID_bikelock.kicad_sch, microcontroller.kicad_sch, power_supply.kicad_sch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]
2026-04-02 fix: resolve state sync deadlocks and enforce password requirement for lock
    - Fix RESET handler sending duplicate notifications (only send once via updateLockState)
    - Enhance BLE status characteristic logging for debugging setValue/notify calls
    - Improve web app BLE decoding to strip null bytes and non-ASCII characters
    - Fix status pattern matching to correctly distinguish LOCKED vs UNLOCKED
    - Add device initialization wait and fresh STATUS request on connection
    - Enforce password requirement before allowing LOCK command (prevents unlock deadlock)
    - Add ERROR_NO_PASSWORD response and web app error handling
    These changes eliminate all remaining deadlock scenarios where buttons could become
    p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
    [main.cpp]
2026-04-06 Switched from LED representation of locked/unlocked state to actual motor driving. Verified that ULN2003 drives stepper motor properly
2026-04-07 Changes: modified schematic - connected stepper pins to gpio. TODO: add footprints and place components
    [RFID_bikelock.kicad_sch]
2026-04-09 Added web files to docs directory for GitHub Pages deployment. Also modified schematic and started pcb placements (not finished)
    [RFID_bikelock.kicad_pcb, RFID_bikelock.kicad_sch]
2026-04-10 Finished PCB placement. Need revision and edge cuts for break-off boards. Need to route tracks
    [RFID_bikelock.kicad_pcb, RFID_bikelock.kicad_sch]
2026-04-13 commit: Migrate BLE to WiFi hotspot with HTTP REST API
    - Removed BLE, implemented WiFi Access Point hotspot mode
    - Created HTTP REST API with 6 endpoints for lock control
    - Built responsive web UI served from SPIFFS
    - Replaced ArduinoJson with manual JSON parsing (size optimization)
    - Firmware: 1.7MB → 1.01MB (77.3% flash usage)
    - Increased sleep timeout: 30s → 5 minutes
    - Fixed GPIO18 wakeup reliability
    Usage: Connect to BikelockAP WiFi → http://192.168.4.1
    [commands.cpp, config.h, lock_control.cpp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]
2026-04-13 Made schematic cleaner - added sections and more description. Ran ERC check and dealt with most of the errors involving power pins.
    [RFID_bikelock.kicad_pcb, RFID_bikelock.kicad_sch]
2026-04-15 Removed old files from SPIFFS implementation, and old web directory that contained the web files for the BLE implementation. They are no longer necessary since we are using HTTP and the esp32 acts as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
2026-04-15 Updated ReadMe.md to match current funcitonality
2026-04-18 Changes: change schematic to use power-path management battery charging, updated codebase to remove traces of old BLE involvement (moved to WIFI). TODO: test deep sleep, fix power delivery in schemat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
    [RFID_bikelock.kicad_pcb, RFID_bikelock.kicad_sch]
2026-04-22 Schematic changes: switched to power-path management for battery charger IC, and buck-boost converter for steady 5v DC output for motor. Also, changed all resistors/capacitors to SMD instead of THT f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
    [RFID_bikelock.kicad_pcb, RFID_bikelock.kicad_sch]
2026-04-22 Final footprint placements BEFORE routing. Commiting just in case routing has errors and we need to move things around. Added mousebite breakaway board for wakeup button.
    [RFID_bikelock.kicad_pcb, RFID_bikelock.kicad_sch]
2026-04-22 Final routing done, DRC clear
    [RFID_bikelock.kicad_pcb]
2026-04-23 Created manufacture files and ordered PCB
    [RFID_bikelock-B_Cu.gbr, RFID_bikelock-B_Mask.gbr, RFID_bikelock-B_Paste.gbr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]
2026-05-07 Added BOM and filled in Manufacturer Product Number fields
    [RFID_bikelock.csv, RFID_bikelock.kicad_sch]
2026-05-14 Added schematic plot pdf
